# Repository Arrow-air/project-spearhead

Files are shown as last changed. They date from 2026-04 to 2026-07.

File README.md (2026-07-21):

# Project Spearhead

**An open-source fixed-wing VTOL aircraft for long-endurance missions.**

Project Spearhead is a ~25 kg MTOW hybrid quadplane developed by
[Arrow](https://arrowair.com): electric motors provide vertical takeoff
and landing, while an internal-combustion pusher engine is intended to provide
efficient long-range cruise.

Spearhead targets long-endurance work such as survey, rural surveillance, and
light cargo. Just as importantly, it is Arrow's first fixed-wing aircraft of
the current era — a deliberate learning platform for fixed-wing sizing, hybrid
propulsion, transition flight, and long-range operations on the path toward
larger aircraft.

## Status

**Phase 1 (electric flight validation) — PT1 prototype build in progress.**

The first prototype is being built in Ankara, Türkiye: laser-cut plywood ribs
and spars, carbon-fiber structure, Oratex fabric skin, 3D-printed structural
connectors, and a fully connectorized electrical harness. PT1 flies electric-only; the
internal-combustion cruise system comes in Phase 2.

The aircraft is still being validated, so requirements and component choices
are provisional unless captured in a dated document in `docs/`.

## Documentation

Start with the [project intro](docs/index.md). The `docs/` folder is the
living engineering record and is published to the Arrow docs site.

| Resource | Description |
|---|---|
| [Electrical Master Document](docs/electrical-master.md) | Full electrical architecture (SPH-E-001) |
| [PT1 Parts List](docs/pt1-parts-list.md) | Electrical procurement for the PT1 build |
| [Information Notes](docs/information-note/) | Aerodynamics and flight-dynamics design notes |
| [Reference Guides](docs/reference-guide/) | Stable technical references (e.g. ArduPilot QuadPlane) |

## Repository structure

```
project-spearhead/
├── docs/                        # Documentation (published to arrowair.com)
│   ├── information-note/        # Dated engineering information notes
│   └── reference-guide/         # Stable technical reference material
└── src/
    └── tools/                   # Engineering tools
        ├── initial_sizing/      # Aircraft sizing studies
        ├── propulsion_model/    # Propulsion modeling
        └── flight_dynamics_model/  # Flight dynamics / stability analysis
```

## Project phases

1. **Electric flight validation** — build and fly the airframe on electric
   VTOL propulsion only; validate hover, transition surfaces, and structure.
2. **Hybrid integration** — add the IC pusher engine, fuel and cooling
   systems; validate vibration handling, transition, and cruise flight.
3. **BVLOS and long-range testing** — telemetry range, lost-link behavior,
   and recovery protocols.
4. **Operational tailoring** — mission configurations (survey/cargo pods),
   operating limits, and a performance manual.

## Getting involved

- Read the [project intro](docs/index.md) and [CONTRIBUTING.md](CONTRIBUTING.md).
- Join the [Arrow Discord](https://discord.gg/arrow) — Spearhead has a weekly
  technical call and active build discussion.
- The original project proposal lives on the
  [Arrow DAO forum](https://dao.arrowair.com/t/project-spearhead-proposal-discussion/153).

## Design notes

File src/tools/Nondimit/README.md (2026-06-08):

# Nondimit v1.1 One Pager

## Purpose

Nondimit is a standalone desktop tool for turning dense aerodynamic force and moment tables into coefficient database files. It is intended for AeroDB and CFD export workflows where the source file contains dimensional forces and moments over alpha and beta, and the final file needs nondimensional body and wind-frame coefficients.

The tool can also reopen an existing Nondimit export and modify it without rerunning CFD. This can be used to move the moment reference center, change the nondimensionalization reference values, or do both in the same saved file.

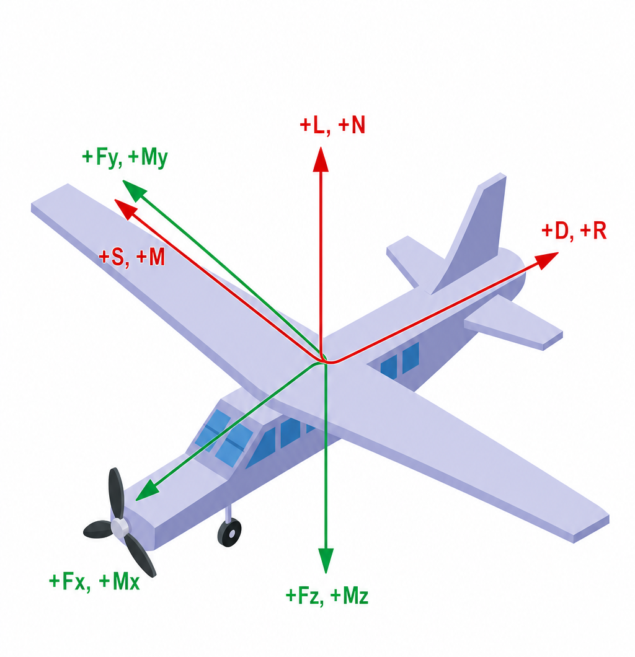
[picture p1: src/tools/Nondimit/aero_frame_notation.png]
Nondimit reference frame notation


The illustration shows the force and moment directions. The table below defines the body and wind-frame notation used by the tool.

| Frame axis | Force name | Moment name | Force coefficient | Moment coefficient | Positive direction |
| --- | --- | --- | --- | --- | --- |
| Body `+x` | `Fx` | `Mx` | `cfx` | `cmx` | Forward toward the nose. |
| Body `+y` | `Fy` | `My` | `cfy` | `cmy` | Toward the aircraft right wing. |
| Body `+z` | `Fz` | `Mz` | `cfz` | `cmz` | Down. |
| Wind `+x` | `D` | `R` | `cd` | `cr` | Aft along the drag direction, opposite the velocity direction. |
| Wind `+y` | `S` | `M` | `cs` | `cm` | Side direction. At zero beta this matches body `+y`. |
| Wind `+z` | `L` | `N` | `cl` | `cn` | Up along the lift direction. |

## Launch

The shared source, README, changelog, version file, and reference-frame image are kept in the Nondimit root folder. Platform-specific package files are separated into `windows/` and `macos/`.

On Windows, open:

```text
windows/Nondimit.exe
```

On macOS, use one of these paths:

- For a packaged app, open the provided `Nondimit.app`.
- For the source folder, run `macos/Start_Nondimit.command`.
- If macOS blocks an unsigned app, use right click, then Open.

The macOS launcher opens the packaged app if present. Otherwise it starts the shared `nondimit.py` source with Python 3.

## Main Workflows

### Convert Raw Table

Use this tab when starting from a raw dense CSV with dimensional force and moment columns.

1. Select the input CSV.
2. Choose the output path.
3. Enter reference values:
   - density `rho`
   - reference area `S`
   - velocity `V`
   - span for roll and yaw moments
   - chord for pitch moment
   - output rounding accuracy
4. Set optional force and moment corrections.
5. Enter old and new moment centers in body-axis coordinates.
6. Confirm column mapping for alpha, beta, `Fx`, `Fy`, `Fz`, and optionally `Mx`, `My`, `Mz`.
7. Set optional beta-zero cleanup and output group order.
8. Click `Convert and Save`.

If moments are mapped, the tool writes force and moment coefficients. If moment columns are not mapped, it writes force coefficients only.

### Modify Export

Use this tab when you already have a coefficient CSV from Nondimit and need to change the moment center, the nondimensionalization reference values, or the output formatting.

1. Select the existing Nondimit export.
2. The tool reads the metadata rows and fills in `rho`, `S`, `V`, span, chord, output accuracy, and current moment center.
3. Edit the reference values if the output should use a different nondimensionalization.
4. Set optional force and moment corrections.
5. Enter the new body-axis moment center if the moment reference should move. Leave it equal to the current center if only the reference values should change.
6. Confirm alpha and beta columns.
7. Set optional beta-zero cleanup and output group order.
8. Click `Modify and Save`.

The current center is read from `moment_center_body_xyz` in the input file metadata. Older exports that used `new_moment_center_body_xyz` still load correctly. New output metadata reports only the final selected moment center, not the previous center.

The reference values in this tab are intentionally editable. When **rho**, **S**, **V**, span, or chord are changed, the tool recalculates all force and moment coefficients with the edited values:

$$
q = \frac{1}{2}\rho V^2
$$

$$
\text{force denominator} = qS
$$

$$
\text{roll and yaw moment denominator} = qSb
$$

$$
\text{pitch moment denominator} = qSc
$$

Normal Nondimit exports include dimensional body force and moment columns, so the tool preserves the physical forces and moments, applies any requested moment-center shift, and then writes new coefficients from the edited reference values. If an export has been manually stripped down to coefficient-only columns, do not use this tab to change reference values, because the physical forces and moments cannot be recovered unambiguously.

## Optional Output Controls

### Force and Moment Corrections

The Corrections section can apply a multiplier and an additive delta to every force and moment component. The correction frame controls which component names are used:

| Frame | Force components | Moment components |
| --- | --- | --- |
| None | no correction | no correction |
| Body | Fx, Fy, Fz | Mx, My, Mz |
| Wind | D, S, L | R, M, N |

Each corrected component is calculated as:

$$
X_{corrected} = m_X X_{original} + \Delta X
$$

For the known missing-component drag correction, use the Wind frame and set D multiplier to 1.3. Leave S, L, R, M, and N multipliers at 1.0 and all deltas at 0.0 unless there is separate calibration evidence for those components.

When the Wind frame is selected, the tool projects the body-axis vector into the wind frame using alpha and beta, applies the selected multipliers and deltas, and reconstructs the body-axis vector before writing the final body and wind columns. This keeps Fx/Fy/Fz and D/S/L internally consistent. Moment corrections work the same way for Mx/My/Mz and R/M/N.

Force corrections are applied before moment-center shifting, so a moment-center shift uses the corrected force vector. Direct moment corrections are applied after the moment-center shift.

### Beta = 0 Cleanup

The checkboxes `Fy`, `Mx`, and `Mz` force those components to zero only on rows where beta is numerically zero. This is useful for symmetric prop-off databases where small solver noise should not create side force, roll moment, or yaw moment at zero sideslip.

The cleanup is applied before coefficients and wind-frame values are written, so body and wind outputs remain internally consistent. Selected cleanup options are stored in metadata as `zero_at_beta0`.

### Output Group Order

The ordered list controls how the generated output columns are arranged. The four groups are:

- Body Forces: `Fx`, `Fy`, `Fz`
- Body Moments: `Mx`, `My`, `Mz`
- Wind Forces: `D`, `S`, `L`
- Wind Moments: `R`, `M`, `N`

Use `Up`, `Down`, and `Reset` to reorder them. Each group keeps its coefficient columns and dimensional columns together. The selected order is stored in metadata as `output_group_order`.

## Coordinate and Coefficient Conventions

The tool uses standard aircraft body axes and aerodynamic wind-axis notation.

Body frame directions are `x` forward, `y` right, and `z` downward. Wind-frame directions are `D` aft along the drag direction, `S` sideways, and `L` upward. The moment symbols `R`, `M`, and `N` are the wind-frame roll, pitch, and yaw moments about those same wind-frame axes.

The generated body coefficient columns are:

```text
cfx, cfy, cfz
cmx, cmy, cmz
```

The generated wind coefficient columns are:

```text
cd, cs, cl
cr, cm, cn
```

The generated dimensional body and wind columns are:

```text
Fx, Fy, Fz
Mx, My, Mz
D, S, L
R, M, N
```

Nondimensionalization and dimensionalization use the reference values written in the export metadata. The dynamic pressure and denominators are:

$$
q = \frac{1}{2}\rho V^2
$$

$$
\text{force denominator} = qS
$$

$$
\text{roll and yaw moment denominator} = qSb
$$

$$
\text{pitch moment denominator} = qSc
$$

Body-axis force coefficients are:

$$
C_{F_x} = \frac{F_x}{qS}
$$

$$
C_{F_y} = \frac{F_y}{qS}
$$

$$
C_{F_z} = \frac{F_z}{qS}
$$

Wind-frame force coefficients are:

$$
C_D = \frac{D}{qS}
$$

$$
C_S = \frac{S_w}{qS}
$$

$$
C_L = \frac{L}{qS}
$$

Body-axis moment coefficients are:

$$
C_{M_x} = \frac{M_x}{qSb}
$$

$$
C_{M_y} = \frac{M_y}{qSc}
$$

$$
C_{M_z} = \frac{M_z}{qSb}
$$

Wind-frame moment coefficients are:

$$
C_R = \frac{R}{qSb}
$$

$$
C_M = \frac{M}{qSc}
$$

$$
C_N = \frac{N}{qSb}
$$

To recover dimensional values from coefficients, use the inverse form:

$$
F_x = C_{F_x}\,qS, \quad F_y = C_{F_y}\,qS, \quad F_z = C_{F_z}\,qS
$$

$$
D = C_D\,qS, \quad S_w = C_S\,qS, \quad L = C_L\,qS
$$

$$
M_x = C_{M_x}\,qSb, \quad M_y = C_{M_y}\,qSc, \quad M_z = C_{M_z}\,qSb
$$

$$
R = C_R\,qSb, \quad M = C_M\,qSc, \quad N = C_N\,qSb
$$

In the equations above, $S_w$ is the wind-frame side force. The corresponding output column is named **S**.

## Moment Center Operation

Moment shifting is done in body axes before coefficient conversion:

$$
\mathbf{M}_{new} = \mathbf{M}_{old} + \mathbf{r}_{new \rightarrow old} \times \mathbf{F}
$$

where:

$$
\mathbf{r}_{new \rightarrow old} = \mathbf{x}_{old\ center} - \mathbf{x}_{new\ center}
$$

After the body-axis moment is shifted, the tool projects both force and moment vectors into the wind frame using the row's alpha and beta.

## Output File

The saved CSV starts with a short readable metadata block, then the normal CSV header row, then table data. The metadata block is intentionally kept to only a few comment rows: reference values, final body-axis moment center, and source/options. It reports only the final moment reference center used by the exported coefficients. Selected correction frame, force multipliers, force deltas, moment multipliers, and moment deltas are stored in the options row.

Generated columns include body and wind-frame coefficients plus dimensional body and wind-frame force and moment columns. Numeric table cells are rounded to the requested output accuracy.

Recommended sanity checks after export:

- Beta-zero rows have `Fy`, `Mx`, and `Mz` equal to zero if those cleanup options were selected.
- Moment signs change as expected when moving the reference center.
- Force and moment correction metadata matches the intended frame, multipliers, and deltas.
- Metadata values match the intended `rho`, `S`, `V`, span, chord, and final moment center.

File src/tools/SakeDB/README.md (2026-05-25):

# SakeDB v1.0 Quick Start

SakeDB is a desktop workflow tool for building aerodynamic databases from high-fidelity analysis cases. It manages the sampling plan, prepares each case folder, launches a user-defined external runner, tracks progress, and exports dense force and moment tables for flight dynamics and control work.

## Purpose

Aerodynamic databases need broad coverage across angle of attack, sideslip, and later control-surface deflections. Running every possible point directly is expensive. SakeDB reduces this cost by combining anchor cases, Latin-hypercube sampling, adaptive infill, and surrogate-surface export into one traceable workflow.

## What It Does

| Function | Role |
|---|---|
| Study setup | Stores variables, bounds, outputs, budgets, anchors, symmetry settings, and runner settings in a **.sakedb** file |
| Case management | Creates one folder per analysis case and records artifacts, status, timing, and output paths |
| Sampling | Runs anchors first, then initial DOE points, then adaptive infill based on uncertainty, curvature, and spacing |
| Pause and resume | Stops or resumes studies without losing completed results |
| Discard control | Lets a bad current or completed case be excluded from surrogate fitting |
| Export | Writes raw results, symmetric results, and dense surrogate tables for downstream coefficient conversion |

## Runner Model

SakeDB is intentionally runner-neutral. A study defines an external runner, a model or mesh file, a setup script, and a launcher script. The launcher is responsible for executing the high-fidelity analysis and writing the expected output files. SakeDB then reads the requested force and moment columns and updates the study database.

The default template does not prefill a solver product or local program path. Each project supplies its own runner settings inside the study folder.

| Setting | Meaning |
|---|---|
| **sim_file** | The base model, mesh, or case file used by the external analysis. Keep it in the study folder for simple relative paths. SakeDB passes its path to the launcher as **SAKEDB_SIM_FILE** and **AERODB_SIM_FILE**. The launcher opens it directly and runs it with the setup file in the case folder |
| **setup_file** | A setup script or template copied into each case folder. SakeDB patches its **alpha** and **beta** definitions for the current sample point before the launcher runs |
| **run_script** | A launcher script copied into each case folder and executed from that folder. It should run the external analysis, write **output.out**, write **output.dat**, and optionally write **force.png** |

The setup script must expose angle definitions in this form so SakeDB can replace the contents for each case:

**double[] alpha = { 0.0 };**

**double[] beta = { 0.0 };**

The important part is the **alpha = { ... };** and **beta = { ... };** pattern. During a run, SakeDB rewrites those values with the current sample, for example **alpha = { -5.0 };** and **beta = { 10.0 };**.

For each sample, SakeDB creates a case folder such as **runs/cases/0007_infill_a-05.000_b+10.000**. That folder contains the patched setup script and copied launcher script. The launcher runs from inside this folder, using the environment variables supplied by SakeDB, and produces the case artifacts there. If a local model or mesh copy is required, the launcher should copy **SAKEDB_SIM_FILE** into the case folder before starting the analysis.

Required and expected case artifacts:

| File | Requirement |
|---|---|
| **output.out** | Text output from the external analysis. This is used for case inspection and troubleshooting |
| **output.dat** | Required force and moment table. It is also the default completion file, so the case is not accepted until it exists |
| **force.png** | Optional force-history image. If produced, it should be named exactly **force.png** so the Force Plot tab can find it |

**output.dat** must contain a **VARIABLES** header followed by numeric rows. The recommended format is:

**VARIABLES = "Beta" "Alpha" "Fx" "Fy" "Fz" "Mx" "My" "Mz"**

**10.0 -5.0 -12.3456 4.5678 -220.1234 0.1000 95.2000 -0.0300**

The force and moment columns **Fx**, **Fy**, **Fz**, **Mx**, **My**, and **Mz** are required. Column names are read from the quoted **VARIABLES** header, and numeric values may use standard decimal or scientific notation. A single final row is sufficient. If several complete rows are written, SakeDB uses the final rows according to the driver averaging setting.

## How To Use

Keep **SakeDB.exe**, **_internal**, **assets**, and **template.sakedb** together in the same folder, then launch **SakeDB.exe**. Use **New** to create a study from the bundled template or **Open** to load an existing **.sakedb** file. Put the model file, setup script, and launcher script beside the study file when you want simple relative paths.

You can also open a study directly from Windows by choosing **Open with** and selecting **SakeDB.exe** for a **.sakedb** file. Windows passes the study path to SakeDB, and SakeDB loads that study at startup. For this to work on another computer, copy the whole SakeDB folder, not only **SakeDB.exe**.

1. Define the study in **Setup**: set the study name, run folder, run budget, convergence stopping options, model file, setup script, launcher script, variables, export grid, and anchor points.
2. Save the study file, then press **Start**. SakeDB runs anchors first, then initial sampling, then adaptive infill.
3. Use **Pause**, **Resume**, and **Stop** from the sidebar to control a campaign. Use **Discard Current Case** when the active case is clearly bad.
4. Review sampled cases in **Samples**. Completed bad cases can be excluded with **Discard Selected Case**.
5. Press **Write Exports** when enough samples are available. SakeDB writes raw, symmetric, and dense surrogate outputs into the run folder.

| Area | Use |
|---|-----|
| Sidebar and status | Select study and run folders, start, pause, resume, stop runs, discard the current case, write exports, refresh the display, switch dark mode, and monitor state, sample count, budget, phase, current case, and stop reason |
| Setup tab | Edit the main study settings without touching YAML directly: budget, convergence threshold, model, setup, launcher files, variable bounds, export grid, anchor values, and extra anchor points |
| Samples tab | View the sample map, live current-case output, and the full results table. The table shows all samples while hiding long artifact paths and internal bookkeeping columns |
| Exports tab | Inspect generated dense export files and preview the dense force or moment table written for downstream flight-dynamics or coefficient-table work |
| Surrogate Surface tab | Select an output component and refresh a fitted surrogate surface to check trends, smoothness, and coverage |
| Force Plot tab | Select a completed case and inspect its per-case force plot when the runner produced one |
| Candidate Scores tab | Show the top current acquisition candidates from the fitted surrogate, including score, uncertainty, curvature, region, spacing, and distance terms |
| Study File tab | Edit or inspect the raw **.sakedb** YAML when an advanced setting is not exposed in the Setup tab |

## Why It Matters

SakeDB turns a large manual simulation campaign into a repeatable database process. The main benefit is not only fewer wasted cases, but cleaner traceability: every sampled point, discarded case, output artifact, symmetry operation, and dense export can be tied back to the study file and run folder.

## Near-Term Next Steps

- Add control-surface deflection dimensions or derivative tables.
- Keep the runner contract generic so future projects can connect different high-fidelity tools without changing the SakeDB workflow.

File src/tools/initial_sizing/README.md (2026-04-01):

# Aerodynamic Sizing Toolchain

Initial aerodynamic sizing for the Spearhead UAV. Determines wing area, tail incidence, cruise drag, and stall behavior for any airfoil combination from a 1,634-airfoil database.

## Quick Start

All inputs are in **`config.py`**. Edit the parameters, set the mode, and run:

```bash
python config.py
```

### Modes

| MODE | What it does |
|---|---|
| 1 | **Airfoil sweep** — tests all airfoil combinations from the database, ranks by composite score, outputs top 30 |
| 2 | **Specific sizing** — runs the sizing tool for the airfoils specified in the `AIRFOIL` dict, prints full results and L/D plots |

## File Structure

| File | Purpose |
|---|---|
| `config.py` | All inputs — aircraft parameters, airfoil selection, sweep filters, scoring weights. Single entry point. |
| `aircraft_sizing.py` | Core sizing solver — atmosphere, wing sizing, trim, drag, stall, alpha sweep |
| `airfoil_sweep.py` | Two-stage airfoil sweep — wing candidates then wing+tail combinations |
| `airfoil_db_re500000.csv` | Airfoil database at Re=500k (1,634 airfoils) |
| `airfoil_db_re1000000.csv` | Airfoil database at Re=1M (1,634 airfoils) |
| `oratex_compatibility.csv` | Airfoil concavity data for Oratex skin filter (generated by `download_geometries.py`) |

## config.py Structure

```
MODE        — 1 (sweep) or 2 (specific sizing)

AIRCRAFT    — shared by both modes
  Atmosphere, flight conditions, MTOW
  Fuselage geometry
  Wing geometry (AR, incidence, CG position)
  Tail configuration (1=V-tail, 2=conventional)
  Tail geometry (span, chord, dihedral, CG position)
  Vertical fin (config 2 only)
  Drag settings (misc factor, base drag recovery)
  Propeller thrust moment
  Tail incidence override

AIRFOIL     — used by MODE 2 (specific sizing)
  Airfoil input mode (1=DB lookup, 2=manual coefficients)
  Wing and tail airfoil names or manual aero coefficients
  Reynolds number

SWEEP       — used by MODE 1 (airfoil sweep)
  Oratex skin filter
  Excluded airfoils list
  Wing filters (cl_max, cd_0, thickness)
  Tail filters (camber, cd_0, thickness)
  Stage control (top wing candidates, skip tail)
  Scoring weights (area, drag, tail incidence, stall)
  Output options (top N, detail rank)
```

## Tail Configuration

### Config 1: V-tail / Inverse V-tail
- `tail_proj_span` = horizontal projected span
- `tail_dihedral` = panel dihedral angle (rad)
- Actual span = projected / cos(dihedral)
- Tail provides both pitch (V_h) and yaw (V_v) authority

### Config 2: Conventional tail
- `tail_proj_span` = full horizontal tail span
- `tail_dihedral` is ignored (set to 0 internally)
- `vert_chord` and `vert_span` define the separate vertical fin for V_v

## Key Equations

- **Wing area**: `S = W / (q_stall * CL_max_3d)`
- **3D lift slope** (Helmbold): `CL_alpha = a0 / (sqrt(1 + k^2) + k)` where `k = a0 / (pi * e * AR)`
- **3D cl_0 correction**: `cl_0_3d = cl_0 * (CL_alpha_3D / cl_alpha_2d)` — preserves zero-lift angle
- **Oswald efficiency** (Raymer): `e = 1.78 * (1 - 0.045 * AR^0.68) - 0.64`
- **Induced drag**: `CDi = CL^2 / (pi * AR * e)`
- **Fuselage drag**: Prandtl-Schlichting friction + Raymer form factor + Hoerner 3D base drag
- **Base drag recovery**: `D_base = D_base_full * (1 - recovery)`, default 34% recovery for pusher prop
- **Downwash**: `epsilon = factor * 2 * CL_wing / (pi * AR)`
- **V_h** (effective): `S_tail * cos(dihedral) * l_tail / (S_wing * c_wing)`
- **V_v**: `S_tail * sin(dihedral) * l_tail / (S_wing * b_wing)` (V-tail) or `S_vert * l_tail / (S_wing * b_wing)` (conventional)

## Sweep Scoring

Candidates are ranked by a weighted composite score (lower = better):

```
Score = w_area * norm(S_wing) + w_drag * norm(D_total) + w_itail * norm(|i_tail|) + w_stall * norm(M_stall_penalty)
```

Default weights (configurable in `config.py`):
- 40% wing area (smaller = lighter)
- 40% total drag (lower = more efficient)
- 10% tail incidence (closer to zero = less trim drag)
- 10% stall safety (nose-down moment preferred)

## Oratex Skin Filter

The Oratex filter excludes airfoils with concave lower surfaces (incompatible with heat-shrink skin). It requires:

1. Airfoil geometry files (`.dat`) in `../geometry/`
2. `oratex_compatibility.csv` — generated by running `download_geometries.py` in the parent `Sizing/` folder

If `oratex_compatibility.csv` is missing, the filter is automatically disabled with a warning. The sweep will still run but won't exclude concave airfoils.

## Dependencies

```
numpy
scipy
matplotlib
```

## CFD Validation

The sizing tool has been validated against RANS CFD and AVL vortex-lattice:
- Lift: within 5-6% of CFD across 0-13 deg AoA
- Drag: within 6% of CFD with the base drag recovery model
- Propeller interaction (actuator disk): confirms base drag recovery assumption

See `aero_validation_note.md` in the parent directory for full details.

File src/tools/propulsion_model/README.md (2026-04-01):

# Propulsion Model

Engine and propeller performance model for the Spearhead UAV. Computes power, thrust, fuel consumption, endurance, and transition (acceleration to cruise) for a 2-stroke gasoline engine with fixed-pitch propeller.

## Quick Start

```bash
python propulsion_model.py
```

Generates an 8-panel figure (`spearhead_engine_model.png`) and prints a console summary with cruise RPM, fuel flow, endurance, rate of climb, and prop comparison table.

## Configuration

All inputs are in the `DEFAULT_CONFIG` dict at the top of `propulsion_model.py`. Pass overrides to `make_plots()` or edit the dict directly.

## Outputs

### Figure (8 subplots)
| Plot | Description |
|---|---|
| Power & Torque vs RPM | Shaft power and torque curves from VE model |
| Static Thrust vs RPM | Multiple prop candidates, anchored to manufacturer data |
| Fuel Consumption vs RPM | Fuel flow from BSFC model |
| Endurance vs Tank Size | Tank sizing for target endurance at cruise |
| Force Balance vs Speed | Thrust and drag curves, net force |
| Airspeed vs Time | Transition simulation (acceleration to cruise) |
| Acceleration vs Speed | Net acceleration during transition |
| Distance vs Time | Ground distance covered during transition |

### Console Summary
- Cruise RPM (where thrust = drag)
- Fuel flow at cruise
- Excess power and max rate of climb
- Battery charging time from excess shaft power
- Prop comparison table across all candidates

## Models and Equations

### Engine Power
```
P = P_rated * (VE(RPM) / VE(RPM_rated)) * (RPM / RPM_rated)
```
- VE shape: quadratic + cubic around peak, asymmetric falloff (faster drop above peak)
- `VE = VE_peak * (1 - 0.55*(x-1)^2 - 0.07*(x-1)^3)` where `x = RPM/RPM_ve_peak`
- Anchored to manufacturer rated HP at rated RPM

### Torque
```
Q = P / omega = (P_kW * 1000) / (RPM * 2*pi/60)
```

### Static Thrust
```
T_static = T_anchor * prop_scale * (rho/rho_anchor) * (RPM/RPM_anchor)^(4/3)
```
- RPM^(4/3) exponent from combined P ~ RPM^2 (2-stroke) and momentum theory T ~ P^(2/3)
- Density ratio referenced to anchor test altitude (not sea level)
- Prop scaling: `(D/D_ref)^(4/3) * (p/p_ref)^(1/3)`

### Thrust in Flight
```
T = T_static * max(0, 1 - (J/J_zero)^2)
```
- Advance ratio: `J = V / (n * D)` where `n = RPM/60`
- Zero-thrust advance ratio: `J_zero = eta_pitch * (p/D)`
- `eta_pitch` = 1.10-1.30 for fixed-pitch props (thrust extends beyond geometric pitch speed)

### Propeller Efficiency
```
eta = eta_max * 4 * x * (1-x)   where x = J/J_zero
```
- Parabolic model peaking at J = 0.5 * J_zero with value eta_max
- eta = 0 at static (J=0) and at zero-thrust (J=J_zero)

### Fuel Consumption
```
fuel_flow [ml/hr] = P_shaft [kW] * BSFC [g/kWh] / 0.74 [kg/L gasoline]
```

### Drag
```
D = D_cruise * (V / V_cruise)^2
```
- Simple quadratic scaling from a single calibration point (from sizing tool)

### Transition Simulation
- 1D horizontal Euler integration, dt = 0.02 s
- `F_net = T(V, RPM) - D(V)`, `a = F_net / mass`, `V += a * dt`

## Assumptions

### Engine
- 2-stroke piston-port timing: VE curve is asymmetric with faster falloff above peak RPM
- Power scales linearly with VE and RPM: `P ~ VE * RPM` (constant displacement)
- BSFC is constant across the operating range (520 g/kWh default)
- No altitude derating on power — only thrust is density-corrected

### Propeller
- Fixed pitch — no variable-pitch or constant-speed governor
- Ct(J) follows a quadratic decay: `1 - (J/J_zero)^2`
- Pitch scaling `(p/p_ref)^(1/3)` is empirical, not derived from BEM theory
- Diameter scaling `(D/D_ref)^(4/3)` assumes engine absorbs prop load at same RPM
- eta_pitch > 1 accounts for real props producing thrust beyond geometric pitch speed
- Propeller efficiency model is a symmetric parabola — real props have an asymmetric eta(J) curve

### Thrust
- Static thrust anchored to a single manufacturer data point (9 kg @ 7900 RPM, 20x10 prop)
- RPM^(4/3) scaling assumes P ~ RPM^2, which is approximate for 2-strokes above torque peak
- Density correction is linear: `T ~ rho` (momentum theory gives `T ~ rho^(1/3)` at constant power, but combined engine+prop gives ~linear)
- No compressibility, no tip Mach effects

### Drag
- Quadratic V^2 scaling from a single point — does not capture the induced drag polar shape
- No density correction on drag (drag_cruise_N is assumed at mission altitude)

### Transition
- Level flight only — no ground roll friction, no climb, no wind
- Constant RPM throughout transition (no throttle modulation)
- Euler integration (first-order, dt = 0.02 s)

## Dependencies

```
numpy
matplotlib
```

## Calibration Data

| Parameter | Value | Source |
|---|---|---|
| Rated HP | 4.1 HP @ 9000 RPM | RCGF Stinger 35cc RE datasheet |
| VE peak RPM | 7500 RPM | Typical for piston-port 2-stroke |
| BSFC | 520 g/kWh | Typical for small 2-stroke (not measured) |
| Anchor thrust | 9 kg @ 7900 RPM | Manufacturer test, 20x10 prop, ~100 m altitude |
| eta_pitch | 1.20 | Typical for fixed-pitch RC props (1.10-1.30) |
| eta_prop_max | 0.70 | Typical for fixed-pitch (0.60-0.75) |
| D_cruise | 30 N @ 25 m/s | From initial sizing tool |

## Validation

### Thermal Efficiency
The model's BSFC of 520 g/kWh yields a thermal efficiency of 16.0%, calculated as:

```
eta_th = 3600 / (BSFC [g/kWh] * LHV [kJ/g])
       = 3600 / (520 * 43.4)
       = 16.0%
```

This is consistent with published data for small piston-port 2-stroke engines:

| Engine class | BSFC (g/kWh) | Thermal eff. |
|---|---|---|
| Small RC 2-stroke (piston-port) | 450 - 600 | 14 - 18% |
| Tuned 2-stroke (DI / stratified) | 320 - 450 | 18 - 26% |
| Small 4-stroke (Saito, OS) | 290 - 370 | 22 - 28% |
| Automotive gasoline | 240 - 280 | 30 - 35% |

The RCGF Stinger 35cc RE is a piston-port 2-stroke with no fuel injection or tuned exhaust, placing it squarely in the 14-18% range. No dyno data is available for this specific engine; the BSFC of 520 g/kWh is an estimate based on the engine class, not a measurement.

### Thrust Anchor
Static thrust is anchored to a single manufacturer test point (9 kg at 7900 RPM with a 20x10 prop at ~100 m altitude). The density ratio correction uses the anchor altitude as reference, so the anchor point reproduces exactly at its test conditions. Thrust at other RPMs and altitudes is extrapolated via the RPM^(4/3) scaling law.

### Cruise RPM
The cruise RPM solver finds the operating point where thrust equals drag at 25 m/s. For the 20x10 prop at 2000 m altitude, this yields ~7000 RPM. No flight test data is available for comparison.

### Limitations
- BSFC is assumed constant across all RPMs. In reality it varies by 20-30% between peak torque and maximum RPM.
- The thrust model has no compressibility or tip Mach correction — valid for tip speeds below ~200 m/s (Mach 0.6).
- The Ct(J) quadratic model is a simplification of the real thrust coefficient curve, which is typically more linear in the mid-J range.
- Propeller efficiency uses a symmetric parabolic model; real eta(J) curves are asymmetric with a sharper cutoff near J_zero.

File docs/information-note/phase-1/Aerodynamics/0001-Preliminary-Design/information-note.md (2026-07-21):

---
title: "Preliminary Exterior Design"
sidebar_label: "Information Note"
sidebar_position: 1
---

## Status

`Valid`

`Revision History: None`

`Replacement Log: None`

`Reference: None`

## Project Description

This information note documents the preliminary exterior design of Project Spearhead. The scope is the outer geometry: fuselage body, main wing, inverse V-tail, and the two longitudinal booms that carry the VTOL lift stations and support the aft tail geometry.

The design is a high-wing quadplane pusher layout. The central fuselage provides the main payload and systems volume. Two longitudinal side booms run parallel to the fuselage centerline and place the four VTOL lift disks around the wing and fuselage. The aft end of the boom system supports the inverse V-tail.

The resulting geometry will be used as a reference for structural design and aerodynamic database generation.

| Isometric view |
|----------------|
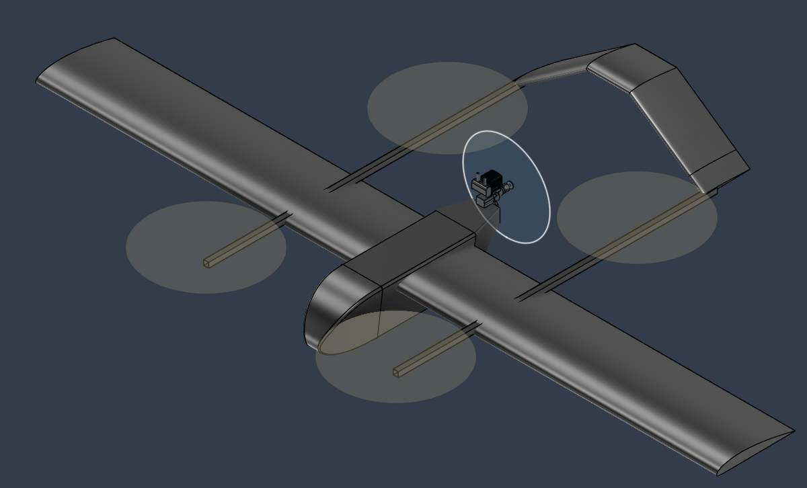
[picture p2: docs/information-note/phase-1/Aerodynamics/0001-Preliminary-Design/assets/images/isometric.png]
Isometric exterior view
|  |

## Methodology

### 1. Fuselage Sizing Method

The fuselage exterior was sized from IC engine placement first. The cylinder was intentionally left outside the fuselage to improve cooling. The engine and exposed cylinder were placed above the aft fuselage and aligned with the upper exterior flow path for cleaner airflow around the cooling region. The IC engine and related systems are covered by the aft fuselage fairing.

The aft taper is intentionally short and sharp. A longer or fuller aft body would block more of the rear pusher propeller inflow, so the body is cut back quickly behind the main volume. Curvature was not added to the aft transition for the prototype because it would make Oratex covering more difficult. This is an accepted prototype compromise and can be smoothed later if needed.

After the IC engine placement, a 12S 16000 mAh battery and a 6 L fuel tank were placed inside the fuselage. The fuel tank was centered on the CG so that the CG does not shift significantly with fuel burn during flight. This section is covered by the mid fuselage fairing.

The nose was then designed to reduce drag while considering weight. The nose houses the avionics if the CG area has no room due to the structural elements.

### 2. Wing and Tail Sizing Method

The main wing and tail geometry were sized using the aerodynamic sizing tool. The tool was used for the main wing airfoil, tail airfoil, planform parameters, incidence values, and the longitudinal spacing between the main wing and tail.

The wing and tail spacing is defined using aerodynamic-center stations relative to the CG. The selected spacing is used with the chosen airfoils and planforms to satisfy cruise trim and tail volume requirements. The tail incidence is then solved by the sizing tool for zero-elevator cruise trim.

### 3. Longitudinal Boom Layout Method

The exterior design uses two straight longitudinal booms, one on each side of the fuselage.

The lateral boom station was checked visually against the top and front views. The longitudinal positioning places the VTOL motor stations around the CG.

### 4. Tail Horizontal Wing Section

Due to the electrical elements and avionics in the tail region, the center of the tail wing is left horizontal. This section provides housing while making the access hatch easier to use.

## Results and Deliverables

### Fuselage Geometry

| Section | Length | Section size |
|---|---|---|
| Nose | About 355 mm | Expands to 240 mm by 275 mm |
| Mid body | About 540 mm | Constant 240 mm by 275 mm |
| Aft body | About 200 mm | Tapers to about 120 mm by 80 mm |
| Total | 1095 mm | 240 mm max width, 275 mm max height |

### Fuselage Sizing Inputs

| Package item | Sizing role |
|---|---|
| IC Engine | 35cc 2-Stroke IC Engine inside the fuselage |
| 12S 16000 mah battery | Primary power source inside fuselage |
| 6 L fuel tank | Cruise fuel source inside fuselage |

### Main Wing Geometry

| Parameter | Value |
|---|---|
| Airfoil | Clark Z |
| Planform | Rectangular, unswept, untapered |
| Gross span | 3.95 m |
| Effective span | 3.65 m |
| Chord | 0.457 m |
| Gross area | 1.805 m2 |
| Effective area | 1.668 m2 |
| Effective aspect ratio | 8.0 |
| Incidence | 1.0 deg |
| Maximum thickness | 54 mm |

### Tail Geometry

| Parameter | Value |
|---|---|
| Tail airfoil | NACA 0015 |
| Tail type | Inverse V-tail |
| Projected span | 1.100 m |
| Geometric span | 1.343 m |
| Chord | 0.28 m |
| Area | 0.376 m2 |
| Dihedral | 35 deg |
| Incidence | 2.0 deg |

### Main and Tail Wings Positioning

| Station | Value |
|---|---|
| Main wing AC relative to CG | 0.15 m forward |
| Tail AC relative to CG | 1.15 m aft |
| Main wing AC to tail AC distance | 1.30 m |

### Longitudinal Boom Layout

| Parameter | Value or description |
|---|---|
| Boom count | 2 |
| Orientation | Longitudinal, parallel to fuselage centerline |
| Lateral station | About 550 mm from centerline |
| Length | 2 m |
| VTOL lift stations | Four total, two per boom, 700 mm longitudinal distance from CG |

| Side view |
|-----------|
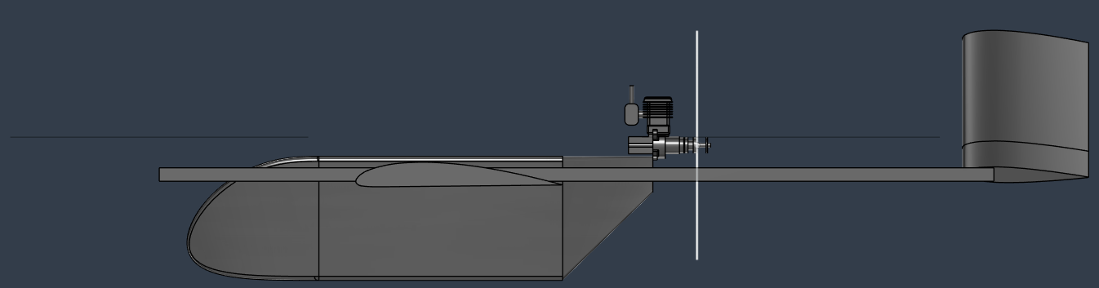
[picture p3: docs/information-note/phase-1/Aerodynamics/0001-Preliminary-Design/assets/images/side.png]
Side exterior view
|  |

| Front view |
|------------|
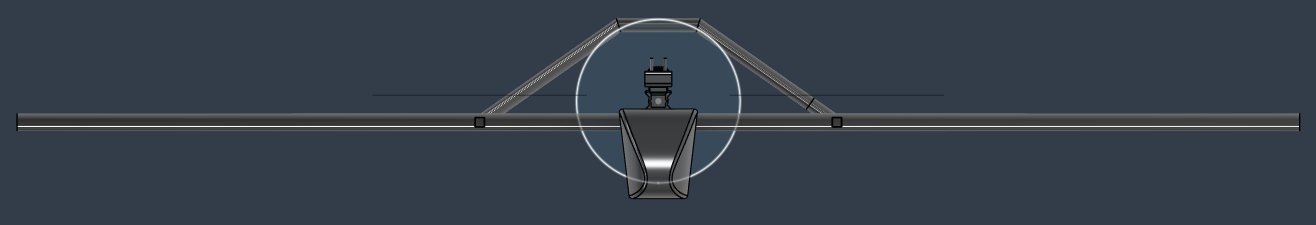
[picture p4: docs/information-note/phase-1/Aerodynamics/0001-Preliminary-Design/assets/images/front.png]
Front exterior view
|  |

| Top view |
|----------|
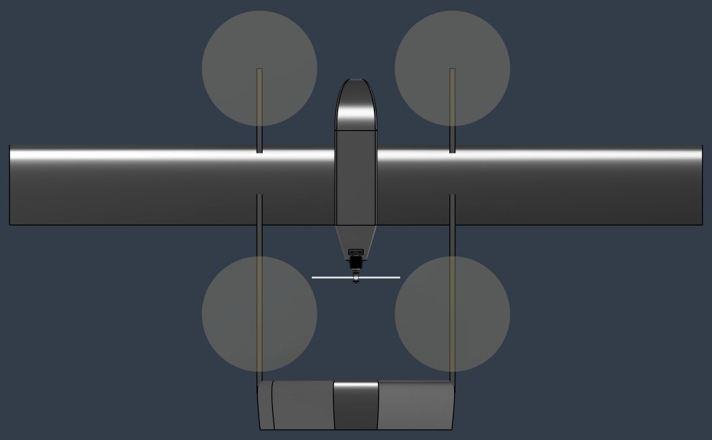
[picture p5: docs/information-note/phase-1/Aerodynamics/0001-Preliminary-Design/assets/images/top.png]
Top exterior view
|  |

### Source Files

| File |
|-----|
| [Fuselage CAD model](assets/fuselage.step) |
| [Main wing CAD model](assets/main_wing.step) |
| [Tail wing CAD model](assets/tail_wing.step) |
| [Longitudinal Booms CAD model](assets/longitudinal_booms.step) |
| [Wing/tail sizing config](assets/config.py) |
| [Wing/tail sizing results](assets/sweep_results_re500000.txt) |

## Remarks

- This note is intentionally limited to exterior geometry and the sizing drivers that define that geometry.
- The sharp aft transition and lack of curvature are known prototype compromises. They are accepted for now to protect rear pusher propeller inflow and simplify Oratex covering.

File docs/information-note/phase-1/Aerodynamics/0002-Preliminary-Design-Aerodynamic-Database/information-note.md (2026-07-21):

---
title: "Preliminary Design Aerodynamic Database"
sidebar_label: "Information Note"
sidebar_position: 1
---

# Preliminary Design Aerodynamic Database

## Status

"Valid"

"Revision History: None"

"Replacement Log: None"

"Reference: [0001-Preliminary-Design](../0001-Preliminary-Design/information-note.md)"

## Project Description

This information note documents the preliminary design aerodynamic database generation work for Project Spearhead. The purpose of the database is to provide force, moment, and coefficient data over the aircraft angle-of-attack and sideslip envelope, so that the results can be used for flight dynamics modelling, control simulation, and later flight-control table generation.

[SakeDB](https://github.com/Arrow-air/project-spearhead/blob/main/src/tools/SakeDB/README.md) was used to define and manage the CFD campaign. First, 80 CFD analyses were solved with the actuator disk model (ADM) simulating the pusher propeller. After that, 800 CFD analyses were solved without the actuator disk model. A surrogate surface was generated from the 800-case database, and the 80-case ADM database was used to apply a correction factor to the surrogate surface. Finally, the corrected dense output was processed with [Nondimit](https://github.com/Arrow-air/project-spearhead/blob/main/src/tools/Nondimit/README.md) for coefficient-table preparation, drag correction for omitted components, and sign-convention checks.

This note does not describe the internal operation of SakeDB or Nondimit. It records how the tools were used in the aerodynamic database workflow and what was delivered.

## Methodology

### 1. CFD Run Methodology

Each database point was solved as a steady incompressible CFD case. The analyses used a segregated flow solver with a K-Omega turbulence model. All Y+ wall treatment was used with five boundary-layer prism layers targeted at Y+ > 30. The computational mesh used approximately 2.7 million polyhedral cells.

Each analysis was run for 350 iterations. The accepted cases reached convergence within this iteration count based on the monitored residual and force histories.

The actuator disk campaign used a prescribed pusher actuator disk thrust of 30 N.

SakeDB was used to manage the selected alpha-beta sample points, launch the external CFD runner, and collect the completed body-axis force and moment outputs: "Fx", "Fy", "Fz", "Mx", "My", and "Mz".

| Figure | Status |
|---|---|
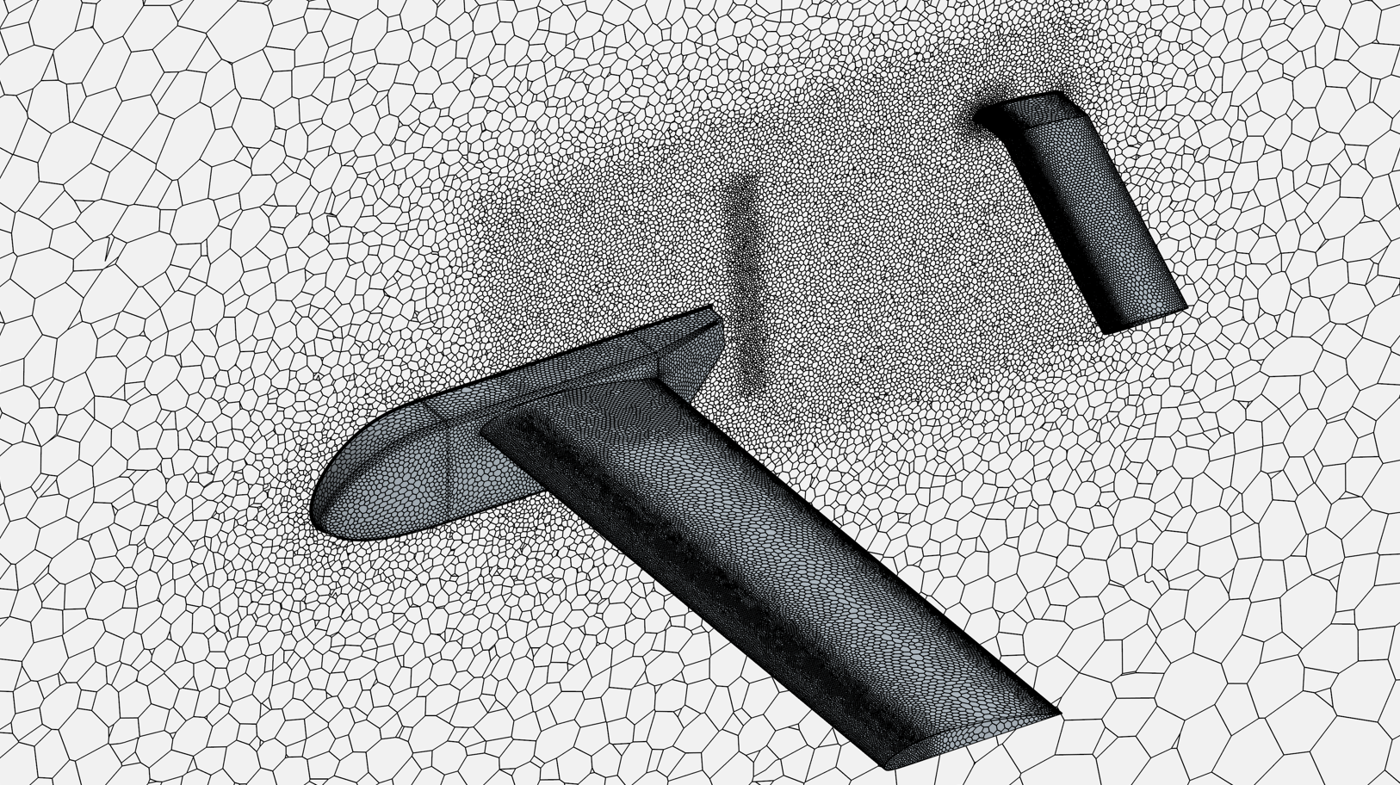
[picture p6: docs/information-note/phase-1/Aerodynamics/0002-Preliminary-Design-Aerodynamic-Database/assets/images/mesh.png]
Mesh Plot
| Mesh plot | |
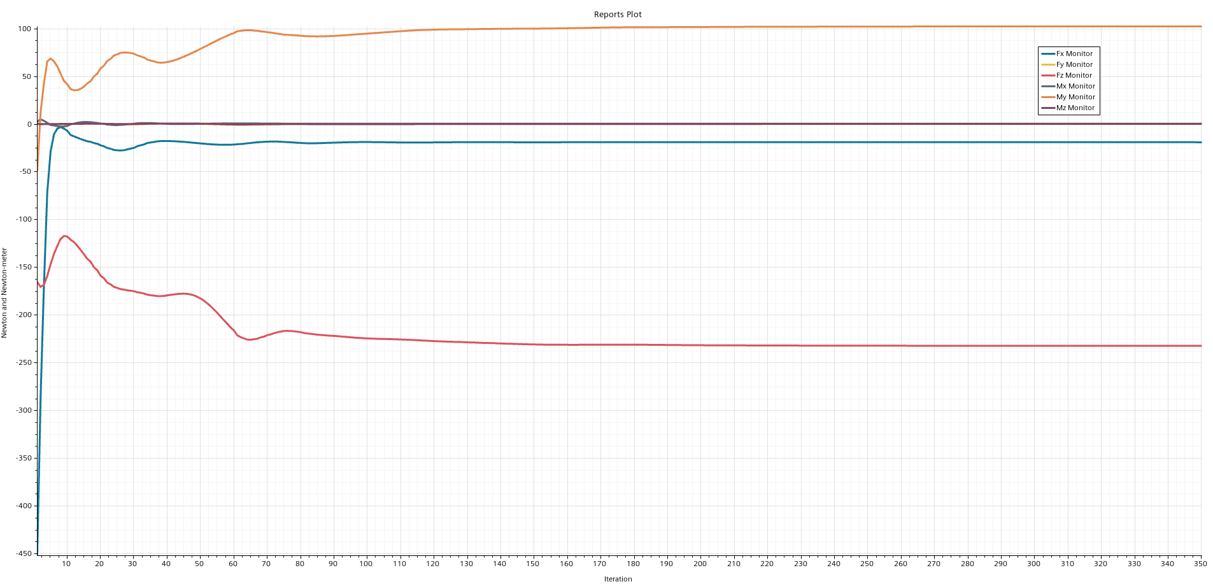
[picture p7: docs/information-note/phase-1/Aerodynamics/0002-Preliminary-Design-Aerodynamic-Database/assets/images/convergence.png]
Convergence Plot
| Convergence plot |  |
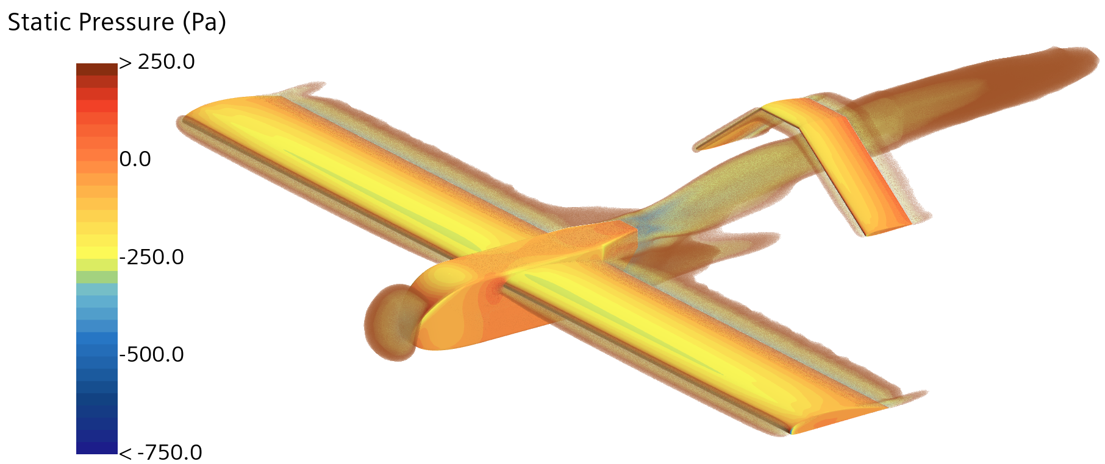
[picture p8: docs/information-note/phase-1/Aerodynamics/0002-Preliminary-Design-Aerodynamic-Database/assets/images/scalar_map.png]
Scalar Map
| Representative CFD result |  |

### 2. Actuator Disk Database

The first database was generated with the actuator disk model. This database includes 80 CFD analyses and is used to capture the aerodynamic effect of the pusher propeller model.

This database is not used as the full final surface by itself. It is used as the correction source for the larger no-actuator-disk surrogate surface.

### 3. No-Actuator-Disk Database

The second database was generated without the actuator disk model. This database includes 800 CFD analyses and covers the broader aircraft angle-of-attack and sideslip envelope.

The no-actuator-disk database is used as the main aerodynamic surface because it has much wider coverage and more sample points than the actuator disk database.

### 4. Surrogate Surface Generation

After the 800-case no-actuator-disk database was completed, a surrogate surface was generated from these results. This surface is used to create a dense aerodynamic table over the complete database range.

The database variables are alpha and beta. The delivered dense grid covers alpha from -90 deg to +90 deg and beta from -90 deg to +90 deg at 1 deg increments, for 181 x 181 points and 32,761 total rows. The exported outputs are dimensional body-axis force and moment components: "Fx", "Fy", "Fz", "Mx", "My", and "Mz".

### 5. Correction Factor Application

The actuator-disk database was then compared with the corresponding no-actuator-disk database values. From this comparison, a correction factor was applied to the surrogate surface.

This correction transfers the propeller model effect from the 80 actuator-disk analyses onto the larger 800-case surrogate surface. The corrected surface is treated as the completed aerodynamic database for this stage.

### 6. Coefficient Output Preparation

The corrected dense force and moment output was then processed with Nondimit. Nondimit was used to convert dimensional body-axis forces and moments into body and wind-frame aerodynamic coefficients, apply the selected moment reference center, and check the drag, lift, side-force, and moment sign conventions.

The coefficient workflow uses body axes with "x" forward, "y" right, and "z" down. Drag is positive aft along the wind direction, lift is positive upward, and side force is positive to the right in the wind-frame convention used by the tool.

The ADM-corrected dense dimensional table uses body-axis coordinates with its moment reference center at (-0.6 m, 0 m, 0 m). The delivered coefficient tables are recentered to the aircraft CG at (-0.15 m, 0 m, 0.15 m) in the same body-axis frame.

A wind-frame drag multiplier of 1.3 was applied during coefficient output preparation to account for known drag-producing components that were not included in the CFD geometry. This correction was applied only to the wind-frame drag component "D". The corrected drag vector was then projected back into body axes so that "Fx", "Fy", "Fz" and "D", "S", "L" remain internally consistent. No independent side-force, lift-force, or direct moment multiplier was applied for this correction.

This drag multiplier is a post-processing correction for the preliminary design aerodynamic database. It is separate from the actuator-disk correction used to transfer pusher propeller effects onto the surrogate surface. This processing step prepares the final coefficient tables for flight dynamics and control-table use.

## Results and Deliverables

### Database Package

The current database package is presented as **ADB v1.1** for the preliminary design aerodynamic database. This keeps the current release tied to the preliminary design stage while leaving room for later project phases to use higher major versions.

Instead of treating every intermediate support table as a deliverable, the database package will provide three primary tables.

| Deliverable | Description |
|---|---|
| [ADM-corrected dense table](assets/dense_table_adm_correction.csv) | No-actuator-disk dense table corrected using the 80-case ADM database |
| [Aerodynamic database](assets/adb_v1_1_no_correction.csv) | ADM-corrected dense table converted into body and wind-frame aerodynamic coefficients with the coefficient tool |
| [Drag-corrected aerodynamic database](assets/adb_v1_1_drag_correction.csv) | Aerodynamic database after the 1.3x drag multiplier for omitted drag-producing components |

The coefficient-table deliverables were generated from the ADM-corrected dense table using Nondimit. If another coefficient format, output group order, reference value set, moment reference center, or correction setup is required, users can reload the ADM-corrected dense table in Nondimit and regenerate the database export. Note that the ADM-corrected dense table moment center is (-0.6 m, 0 m, 0 m) in body-axis coordinates. The delivered coefficient tables are referenced to the aircraft CG at (-0.15 m, 0 m, 0.15 m).

| Drag | Lift |
|---|---|
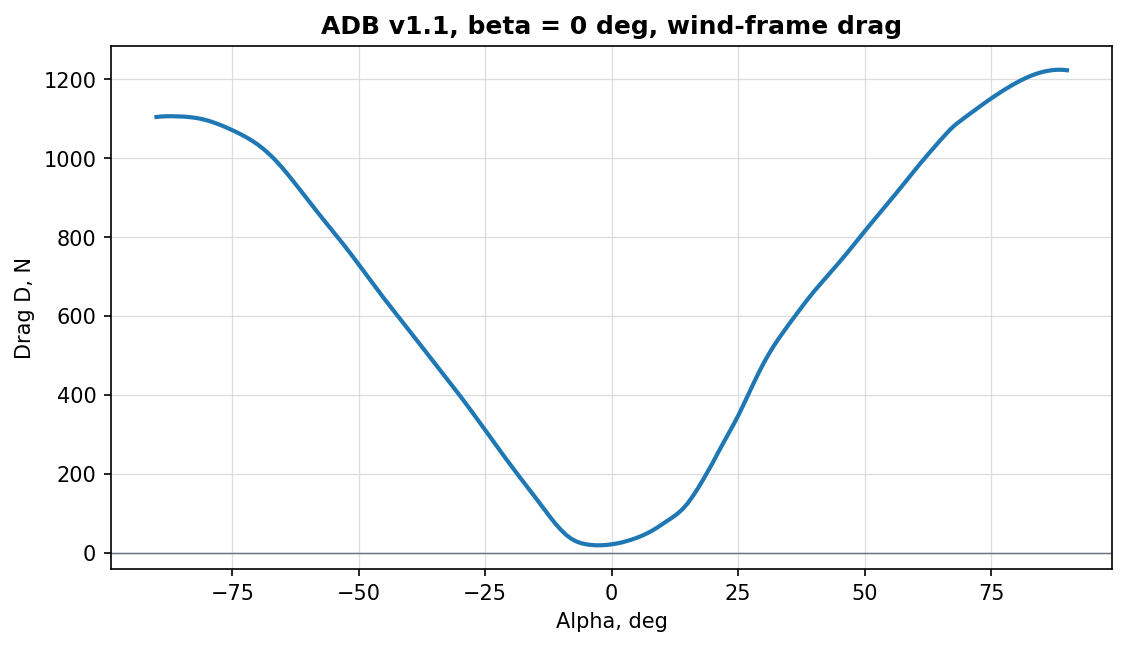
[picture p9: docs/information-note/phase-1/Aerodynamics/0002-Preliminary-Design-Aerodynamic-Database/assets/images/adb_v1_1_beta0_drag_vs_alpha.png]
Beta 0 drag versus alpha
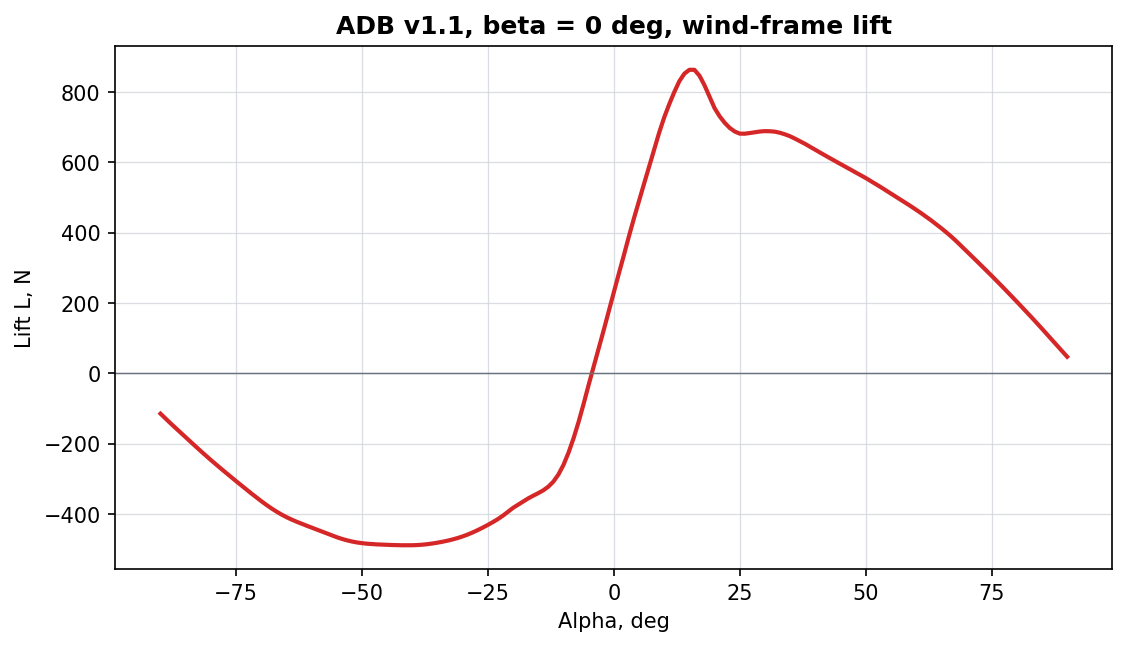
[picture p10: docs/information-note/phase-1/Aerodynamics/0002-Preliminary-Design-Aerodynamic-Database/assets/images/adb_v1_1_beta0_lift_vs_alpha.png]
Beta 0 lift versus alpha
|  |  | 
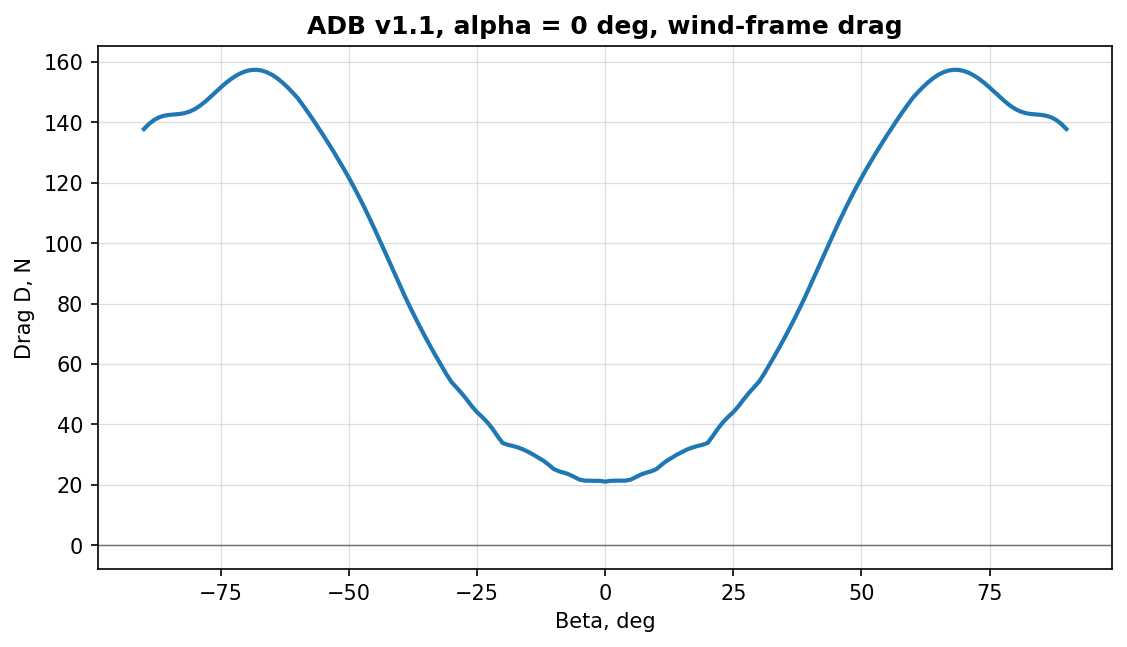
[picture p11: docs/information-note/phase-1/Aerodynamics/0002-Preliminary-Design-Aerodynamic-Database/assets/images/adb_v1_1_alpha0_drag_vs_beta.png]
Alpha 0 drag versus beta
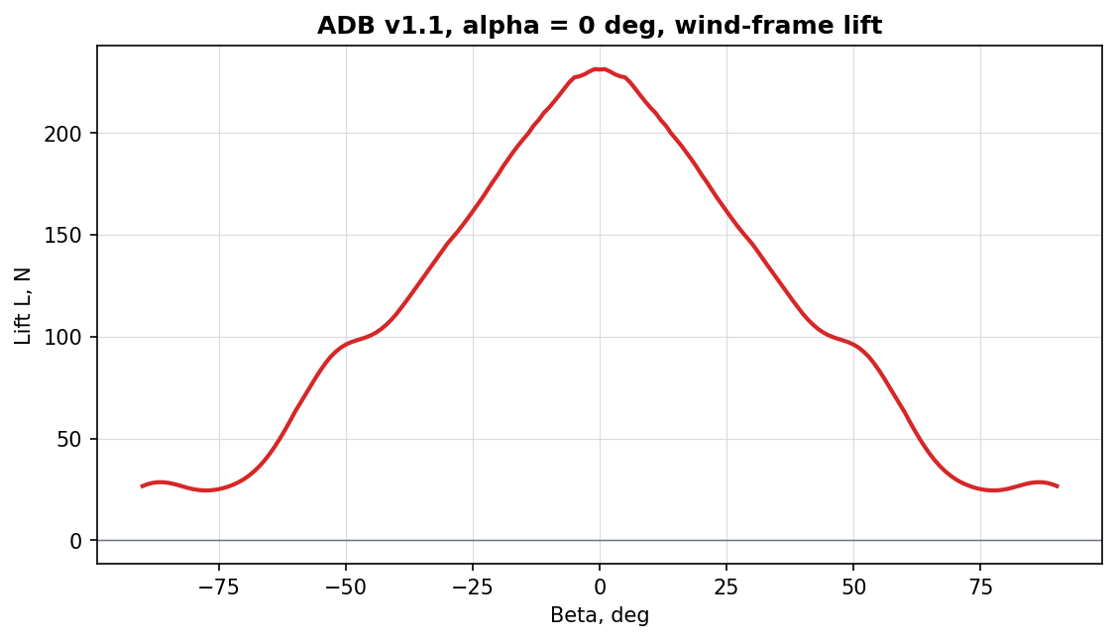
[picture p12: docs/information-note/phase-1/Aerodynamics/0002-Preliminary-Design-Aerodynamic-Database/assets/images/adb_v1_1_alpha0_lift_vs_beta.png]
Alpha 0 lift versus beta
| | |

### How to Use the Database

For preliminary design, flight-dynamics modelling, and control-table preparation, it is recommended to use **Drag-corrected aerodynamic database** as the main aerodynamic database. The 1.3x wind-frame drag multiplier was applied to cover known drag-producing equipment and installation details that were omitted from the CFD geometry. This gives a more conservative drag estimate for the current design stage and should be revisited when those components are modelled directly or when higher-fidelity validation data becomes available.

The coefficient table is organized by alpha and beta in degrees. The delivered coefficient grid covers alpha from -90 deg to +90 deg and beta from -90 deg to +90 deg at 1 deg increments, for 32,761 total rows. Users should interpolate within the provided alpha-beta grid and avoid extrapolating outside this range. The coefficient columns are dimensionless and should be dimensionalized using the reference values below.

| Reference | Symbol | Value |
|---|---|---|
| Air density | $$\rho$$ | 1.09 kg/m^3 |
| Reference velocity | $$V$$ | 25 m/s |
| Dynamic pressure | $$q = 0.5 \rho V^{2}$$ | 340.625 Pa |
| Reference area | $$S$$ | 1.805 m^2 |
| Reference span | $$b$$ | 3.95 m |
| Reference chord | $$c$$ | 0.457 m |
| Force denominator | $$qS$$ | 614.8281 N |
| Roll and yaw moment denominator | $$qSb$$ | 2428.5711 N m |
| Pitch moment denominator | $$qSc$$ | 280.9765 N m |
| Moment reference center / CG, body x y z | $$(x_m, y_m, z_m)$$ | -0.15 m, 0 m, 0.15 m |

The density value corresponds to the database run condition at 1200 m altitude.

The dynamic pressure and denominators are:

$$
q = \frac{1}{2} \rho V^{2}
$$

Wind-frame forces are dimensionalized as:

$$
D = C_D qS
$$

$$
S_w = C_S qS
$$

$$
L = C_L qS
$$

Body-axis forces are dimensionalized as:

$$
F_x = C_{F_x} qS
$$

$$
F_y = C_{F_y} qS
$$

$$
F_z = C_{F_z} qS
$$

Body-axis moments are dimensionalized as:

$$
M_x = C_{M_x} qSb
$$

$$
M_y = C_{M_y} qSc
$$

$$
M_z = C_{M_z} qSb
$$

Wind-frame moments are dimensionalized as:

$$
R = C_R qSb
$$

$$
M = C_M qSc
$$

$$
N = C_N qSb
$$

The corresponding coefficient columns in the delivered CSV are **cd**, **cs**, **cl**, **cfx**, **cfy**, **cfz**, **cmx**, **cmy**, **cmz**, **cr**, **cm**, and **cn**.

| Reference frame notation |
|--------------------------|
| Nondimit reference frame notation |

Body-axis outputs should be used when the receiving flight-dynamics model expects aircraft body axes. The body-axis convention is x forward, y right, and z down. Wind-frame outputs should be used for aerodynamic review and sign-convention checks. In the wind-frame convention used here, drag is positive aft along the wind direction, lift is positive upward, and side force is positive to the right.

If a different moment reference center, reference area, span, chord, density, or velocity is required, the table should be regenerated with Nondimit instead of manually editing the moment coefficient columns. Note that the ADM-corrected dense table moment center is (-0.6 m, 0 m, 0 m) in body-axis coordinates. The delivered coefficient tables are referenced to the aircraft CG at (-0.15 m, 0 m, 0.15 m).

## Remarks

- The actuator-disk correction and the 1.3x omitted-component drag correction are accepted for the current aerodynamic database stage.
- Preliminary pitch-moment trends indicate that the aircraft is not statically stable at the current coefficient-table CG reference by itself. This is expected to be addressed through CG placement, and the longitudinal stability analysis will define the allowable CG range and target CG location.
- This database will be updated with the control surface deflections once available.

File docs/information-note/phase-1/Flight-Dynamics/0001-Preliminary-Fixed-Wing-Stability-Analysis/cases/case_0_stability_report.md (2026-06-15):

# Case 0 Stability Report

> Preliminary FDM result: inertia, control derivatives, rate damping, and propulsion are placeholders; ADB v1.1 contains alpha-beta data only.

## Database Metadata

- File: `adb_v1_1_drag_correction_0.csv`
- Moment/reference/CG: `(-0.000, 0.000, 0.150) m`
- rho: `1.090 kg/m^3`, q_ref: `340.625 Pa`, S: `1.805 m^2`, b: `3.950 m`, c: `0.457 m`

## Trim

- success: `True`
- alpha: `2.2937 deg`
- theta: `2.2937 deg`
- elevator: `-9.7286 deg`
- throttle: `0.1719`
- residual norm: `1.415e-14`

## Static Stability Derivatives

- Cm_alpha: `-1.037054 /rad` (stable longitudinal static sign)
- Cn_beta: `+0.034377 /rad` (stable directional static sign)
- Cl_beta: `-0.013984 /rad` (stable lateral static sign)
- CL_alpha: `+5.001922 /rad`
- CY_beta: `-0.228001 /rad`

## Dynamic Modes

| Mode | Eigenvalues | wn rad/s | zeta | time constant s | Classification |
|---|---:|---:|---:|---:|---|
| phugoid | `-0.0253188+0.540732j; -0.0253188-0.540732j` | 0.5413 | 0.0468 | 39.4963 | stable |
| short_period | `-4.45612+7.50931j; -4.45612-7.50931j` | 8.7319 | 0.5103 | 0.2244 | stable |
| dutch-roll-like lateral-directional | `No clearly identifiable Dutch-roll-like lateral-directional oscillatory mode was found in this linearization.` | n/a | n/a | n/a | not identified |
| roll | `-30.2252+0j` | 30.2252 | 1.0000 | 0.0331 | stable |
| spiral | `-0.00285347+0j` | 0.0029 | 1.0000 | 350.4503 | stable |

## Summary

- Static stability: longitudinal `stable`, directional `stable`, lateral `stable`.
- Dynamic stability among identified reduced-order modes: `stable`.
- Weakly damped modes: phugoid.
- No clearly identifiable Dutch-roll-like lateral-directional oscillatory mode was found in this linearization. Because the aircraft uses an inverse V-tail/ruddervator layout and the current lateral reduced eigenspectrum is entirely real, treat this as a model limitation and classification ambiguity to investigate before flight-test use.

## Conclusion

Case 0 is the most stable sampled case by longitudinal static and dynamic metrics, but it requires the largest elevator trim deflection. It should be treated as a forward stability bound until control authority, mass properties, and the full control model are validated.

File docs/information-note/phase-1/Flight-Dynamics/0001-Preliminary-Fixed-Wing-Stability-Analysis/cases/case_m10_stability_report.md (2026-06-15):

# Case M10 Stability Report

> Preliminary FDM result: inertia, control derivatives, rate damping, and propulsion are placeholders; ADB v1.1 contains alpha-beta data only.

## Database Metadata

- File: `adb_v1_1_drag_correction_m10.csv`
- Moment/reference/CG: `(-0.100, 0.000, 0.150) m`
- rho: `1.090 kg/m^3`, q_ref: `340.625 Pa`, S: `1.805 m^2`, b: `3.950 m`, c: `0.457 m`

## Trim

- success: `True`
- alpha: `1.7432 deg`
- theta: `1.7432 deg`
- elevator: `-1.8846 deg`
- throttle: `0.1608`
- residual norm: `5.859e-14`

## Static Stability Derivatives

- Cm_alpha: `+0.446907 /rad` (unstable longitudinal static sign)
- Cn_beta: `+0.028648 /rad` (stable directional static sign)
- Cl_beta: `-0.010723 /rad` (stable lateral static sign)
- CL_alpha: `+4.858682 /rad`
- CY_beta: `-0.227790 /rad`

## Dynamic Modes

| Mode | Eigenvalues | wn rad/s | zeta | time constant s | Classification |
|---|---:|---:|---:|---:|---|
| phugoid | `-0.32842+0.893381j; -0.32842-0.893381j` | 0.9518 | 0.3450 | 3.0449 | stable |
| short_period | `-9.31431+0j; +1.1421+0j` | 1.1421 | -1.0000 | 0.8756 | unstable |
| dutch-roll-like lateral-directional | `No clearly identifiable Dutch-roll-like lateral-directional oscillatory mode was found in this linearization.` | n/a | n/a | n/a | not identified |
| roll | `-30.2281+0j` | 30.2281 | 1.0000 | 0.0331 | stable |
| spiral | `+0.000287463+0j` | 0.0003 | -1.0000 | 3478.7093 | unstable |

## Summary

- Static stability: longitudinal `unstable`, directional `stable`, lateral `stable`.
- Dynamic stability among identified reduced-order modes: `unstable`.
- Unstable modes: short_period, spiral.
- No clearly identifiable Dutch-roll-like lateral-directional oscillatory mode was found in this linearization. Because the aircraft uses an inverse V-tail/ruddervator layout and the current lateral reduced eigenspectrum is entirely real, treat this as a model limitation and classification ambiguity to investigate before flight-test use.

## Conclusion

Case M10 improves the longitudinal trend relative to nominal but remains unsuitable as a stability baseline. The pitch static derivative is still unstable, the longitudinal dynamic response is unstable, and the spiral mode is weakly unstable in this linearization.

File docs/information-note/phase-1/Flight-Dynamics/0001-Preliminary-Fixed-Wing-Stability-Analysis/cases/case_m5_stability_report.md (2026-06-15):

# Case M5 Stability Report

> Preliminary FDM result: inertia, control derivatives, rate damping, and propulsion are placeholders; ADB v1.1 contains alpha-beta data only.

## Database Metadata

- File: `adb_v1_1_drag_correction_m5.csv`
- Moment/reference/CG: `(-0.050, 0.000, 0.150) m`
- rho: `1.090 kg/m^3`, q_ref: `340.625 Pa`, S: `1.805 m^2`, b: `3.950 m`, c: `0.457 m`

## Trim

- success: `True`
- alpha: `2.0061 deg`
- theta: `2.0061 deg`
- elevator: `-5.5737 deg`
- throttle: `0.1665`
- residual norm: `4.705e-14`

## Static Stability Derivatives

- Cm_alpha: `-0.291354 /rad` (stable longitudinal static sign)
- Cn_beta: `+0.028665 /rad` (stable directional static sign)
- Cl_beta: `-0.011511 /rad` (stable lateral static sign)
- CL_alpha: `+4.932043 /rad`
- CY_beta: `-0.226353 /rad`

## Dynamic Modes

| Mode | Eigenvalues | wn rad/s | zeta | time constant s | Classification |
|---|---:|---:|---:|---:|---|
| phugoid | `-0.024601+0.474923j; -0.024601-0.474923j` | 0.4756 | 0.0517 | 40.6487 | stable |
| short_period | `-4.45504+5.15473j; -4.45504-5.15473j` | 6.8131 | 0.6539 | 0.2245 | stable |
| dutch-roll-like lateral-directional | `No clearly identifiable Dutch-roll-like lateral-directional oscillatory mode was found in this linearization.` | n/a | n/a | n/a | not identified |
| roll | `-30.2267+0j` | 30.2267 | 1.0000 | 0.0331 | stable |
| spiral | `-0.00364264+0j` | 0.0036 | 1.0000 | 274.5265 | stable |

## Summary

- Static stability: longitudinal `stable`, directional `stable`, lateral `stable`.
- Dynamic stability among identified reduced-order modes: `stable`.
- Weakly damped modes: phugoid.
- No clearly identifiable Dutch-roll-like lateral-directional oscillatory mode was found in this linearization. Because the aircraft uses an inverse V-tail/ruddervator layout and the current lateral reduced eigenspectrum is entirely real, treat this as a model limitation and classification ambiguity to investigate before flight-test use.

## Conclusion

Case M5 is the recommended near-term development baseline from this sweep. It preserves stable identified longitudinal behavior with more margin than M5p5 while staying near the transition region that should be refined in future CG studies.

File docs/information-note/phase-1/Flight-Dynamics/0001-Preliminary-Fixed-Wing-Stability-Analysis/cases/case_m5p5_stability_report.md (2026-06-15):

# Case M5p5 Stability Report

> Preliminary FDM result: inertia, control derivatives, rate damping, and propulsion are placeholders; ADB v1.1 contains alpha-beta data only.

## Database Metadata

- File: `adb_v1_1_drag_correction_m5p5.csv`
- Moment/reference/CG: `(-0.055, 0.000, 0.150) m`
- rho: `1.090 kg/m^3`, q_ref: `340.625 Pa`, S: `1.805 m^2`, b: `3.950 m`, c: `0.457 m`

## Trim

- success: `True`
- alpha: `1.9787 deg`
- theta: `1.9787 deg`
- elevator: `-5.1878 deg`
- throttle: `0.1659`
- residual norm: `2.463e-14`

## Static Stability Derivatives

- Cm_alpha: `-0.214751 /rad` (stable longitudinal static sign)
- Cn_beta: `+0.028648 /rad` (stable directional static sign)
- Cl_beta: `-0.011398 /rad` (stable lateral static sign)
- CL_alpha: `+4.924211 /rad`
- CY_beta: `-0.226440 /rad`

## Dynamic Modes

| Mode | Eigenvalues | wn rad/s | zeta | time constant s | Classification |
|---|---:|---:|---:|---:|---|
| phugoid | `-0.04536+0.166775j; -0.04536-0.166775j` | 0.1728 | 0.2624 | 22.0459 | stable |
| short_period | `-4.37067+1.2534j; -4.37067-1.2534j` | 4.5468 | 0.9613 | 0.2288 | stable |
| dutch-roll-like lateral-directional | `No clearly identifiable Dutch-roll-like lateral-directional oscillatory mode was found in this linearization.` | n/a | n/a | n/a | not identified |
| roll | `-30.2268+0j` | 30.2268 | 1.0000 | 0.0331 | stable |
| spiral | `-0.00305176+0j` | 0.0031 | 1.0000 | 327.6796 | stable |

## Summary

- Static stability: longitudinal `stable`, directional `stable`, lateral `stable`.
- Dynamic stability among identified reduced-order modes: `stable`.
- No clearly identifiable Dutch-roll-like lateral-directional oscillatory mode was found in this linearization. Because the aircraft uses an inverse V-tail/ruddervator layout and the current lateral reduced eigenspectrum is entirely real, treat this as a model limitation and classification ambiguity to investigate before flight-test use.

## Conclusion

Case M5p5 is the first sampled case with stable static pitch behavior and stable identified longitudinal modes. It should be treated as the current sampled aft boundary of the stable region rather than as a high-margin baseline.

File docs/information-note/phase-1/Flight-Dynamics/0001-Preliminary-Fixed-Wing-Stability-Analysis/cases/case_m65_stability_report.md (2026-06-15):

# Case M65 Stability Report

> Preliminary FDM result: inertia, control derivatives, rate damping, and propulsion are placeholders; ADB v1.1 contains alpha-beta data only.

## Database Metadata

- File: `adb_v1_1_drag_correction_m65.csv`
- Moment/reference/CG: `(-0.065, 0.000, 0.150) m`
- rho: `1.090 kg/m^3`, q_ref: `340.625 Pa`, S: `1.805 m^2`, b: `3.950 m`, c: `0.457 m`

## Trim

- success: `True`
- alpha: `1.9248 deg`
- theta: `1.9248 deg`
- elevator: `-4.4307 deg`
- throttle: `0.1647`
- residual norm: `2.276e-14`

## Static Stability Derivatives

- Cm_alpha: `-0.065699 /rad` (stable longitudinal static sign)
- Cn_beta: `+0.028648 /rad` (stable directional static sign)
- Cl_beta: `-0.011244 /rad` (stable lateral static sign)
- CL_alpha: `+4.908748 /rad`
- CY_beta: `-0.226749 /rad`

## Dynamic Modes

| Mode | Eigenvalues | wn rad/s | zeta | time constant s | Classification |
|---|---:|---:|---:|---:|---|
| short_period | `-6.39647+0j; -2.24543+0j; -0.442251+0j; +0.252802+0j` | 0.2528 | -1.0000 | 3.9557 | unstable |
| dutch-roll-like lateral-directional | `No clearly identifiable Dutch-roll-like lateral-directional oscillatory mode was found in this linearization.` | n/a | n/a | n/a | not identified |
| roll | `-30.2271+0j` | 30.2271 | 1.0000 | 0.0331 | stable |
| spiral | `-0.00228627+0j` | 0.0023 | 1.0000 | 437.3945 | stable |

## Summary

- Static stability: longitudinal `stable`, directional `stable`, lateral `stable`.
- Dynamic stability among identified reduced-order modes: `unstable`.
- Unstable modes: short_period.
- No clearly identifiable Dutch-roll-like lateral-directional oscillatory mode was found in this linearization. Because the aircraft uses an inverse V-tail/ruddervator layout and the current lateral reduced eigenspectrum is entirely real, treat this as a model limitation and classification ambiguity to investigate before flight-test use.

## Conclusion

Case M65 is the first sampled case with the stable sign for pitch static stability, but it is not dynamically acceptable. It helps bracket the transition region between static stability and fully stable identified longitudinal dynamics.

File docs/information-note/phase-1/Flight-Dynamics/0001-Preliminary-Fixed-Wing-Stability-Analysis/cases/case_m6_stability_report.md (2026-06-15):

# Case M6 Stability Report

> Preliminary FDM result: inertia, control derivatives, rate damping, and propulsion are placeholders; ADB v1.1 contains alpha-beta data only.

## Database Metadata

- File: `adb_v1_1_drag_correction_m6.csv`
- Moment/reference/CG: `(-0.060, 0.000, 0.150) m`
- rho: `1.090 kg/m^3`, q_ref: `340.625 Pa`, S: `1.805 m^2`, b: `3.950 m`, c: `0.457 m`

## Trim

- success: `True`
- alpha: `1.9516 deg`
- theta: `1.9516 deg`
- elevator: `-4.8077 deg`
- throttle: `0.1653`
- residual norm: `2.371e-14`

## Static Stability Derivatives

- Cm_alpha: `-0.138827 /rad` (stable longitudinal static sign)
- Cn_beta: `+0.028648 /rad` (stable directional static sign)
- Cl_beta: `-0.011321 /rad` (stable lateral static sign)
- CL_alpha: `+4.916448 /rad`
- CY_beta: `-0.226595 /rad`

## Dynamic Modes

| Mode | Eigenvalues | wn rad/s | zeta | time constant s | Classification |
|---|---:|---:|---:|---:|---|
| short_period | `-5.50085+0j; -3.20677+0j; -0.240531+0j; +0.116444+0j` | 0.1164 | -1.0000 | 8.5878 | unstable |
| dutch-roll-like lateral-directional | `No clearly identifiable Dutch-roll-like lateral-directional oscillatory mode was found in this linearization.` | n/a | n/a | n/a | not identified |
| roll | `-30.227+0j` | 30.2270 | 1.0000 | 0.0331 | stable |
| spiral | `-0.00266744+0j` | 0.0027 | 1.0000 | 374.8912 | stable |

## Summary

- Static stability: longitudinal `stable`, directional `stable`, lateral `stable`.
- Dynamic stability among identified reduced-order modes: `unstable`.
- Unstable modes: short_period.
- No clearly identifiable Dutch-roll-like lateral-directional oscillatory mode was found in this linearization. Because the aircraft uses an inverse V-tail/ruddervator layout and the current lateral reduced eigenspectrum is entirely real, treat this as a model limitation and classification ambiguity to investigate before flight-test use.

## Conclusion

Case M6 is statically stable in pitch but still dynamically unstable. It sits close to the dynamic stability transition and is useful for bounding the aft side of the stable region.

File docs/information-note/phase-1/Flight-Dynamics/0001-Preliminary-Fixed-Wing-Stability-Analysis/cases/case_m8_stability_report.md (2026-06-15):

# Case M8 Stability Report

> Preliminary FDM result: inertia, control derivatives, rate damping, and propulsion are placeholders; ADB v1.1 contains alpha-beta data only.

## Database Metadata

- File: `adb_v1_1_drag_correction_m8.csv`
- Moment/reference/CG: `(-0.080, 0.000, 0.150) m`
- rho: `1.090 kg/m^3`, q_ref: `340.625 Pa`, S: `1.805 m^2`, b: `3.950 m`, c: `0.457 m`

## Trim

- success: `True`
- alpha: `1.8458 deg`
- theta: `1.8458 deg`
- elevator: `-3.3242 deg`
- throttle: `0.1630`
- residual norm: `3.985e-14`

## Static Stability Derivatives

- Cm_alpha: `+0.155594 /rad` (unstable longitudinal static sign)
- Cn_beta: `+0.028648 /rad` (stable directional static sign)
- Cl_beta: `-0.011018 /rad` (stable lateral static sign)
- CL_alpha: `+4.886141 /rad`
- CY_beta: `-0.227202 /rad`

## Dynamic Modes

| Mode | Eigenvalues | wn rad/s | zeta | time constant s | Classification |
|---|---:|---:|---:|---:|---|
| phugoid | `-0.745163+0.728641j; -0.745163-0.728641j` | 1.0422 | 0.7150 | 1.3420 | stable |
| short_period | `-7.91482+0j; +0.574806+0j` | 0.5748 | -1.0000 | 1.7397 | unstable |
| dutch-roll-like lateral-directional | `No clearly identifiable Dutch-roll-like lateral-directional oscillatory mode was found in this linearization.` | n/a | n/a | n/a | not identified |
| roll | `-30.2275+0j` | 30.2275 | 1.0000 | 0.0331 | stable |
| spiral | `-0.00116757+0j` | 0.0012 | 1.0000 | 856.4773 | stable |

## Summary

- Static stability: longitudinal `unstable`, directional `stable`, lateral `stable`.
- Dynamic stability among identified reduced-order modes: `unstable`.
- Unstable modes: short_period.
- No clearly identifiable Dutch-roll-like lateral-directional oscillatory mode was found in this linearization. Because the aircraft uses an inverse V-tail/ruddervator layout and the current lateral reduced eigenspectrum is entirely real, treat this as a model limitation and classification ambiguity to investigate before flight-test use.

## Conclusion

Case M8 is close to the static pitch-stability transition but has not crossed into acceptable behavior. It remains statically unstable in pitch and dynamically unstable in the identified longitudinal response.

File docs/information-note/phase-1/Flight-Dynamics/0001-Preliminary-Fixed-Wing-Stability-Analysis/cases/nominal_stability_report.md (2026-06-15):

# Nominal Stability Report

> Preliminary FDM result: inertia, control derivatives, rate damping, and propulsion are placeholders; ADB v1.1 contains alpha-beta data only.

## Database Metadata

- File: `adb_v1_1_drag_correction.csv`
- Moment/reference/CG: `(-0.150, 0.000, 0.150) m`
- rho: `1.090 kg/m^3`, q_ref: `340.625 Pa`, S: `1.805 m^2`, b: `3.950 m`, c: `0.457 m`

## Trim

- success: `True`
- alpha: `1.5005 deg`
- theta: `1.5005 deg`
- elevator: `1.5157 deg`
- throttle: `0.1563`
- residual norm: `1.279e-13`

## Static Stability Derivatives

- Cm_alpha: `+0.985487 /rad` (unstable longitudinal static sign)
- Cn_beta: `+0.024349 /rad` (stable directional static sign)
- Cl_beta: `-0.010028 /rad` (stable lateral static sign)
- CL_alpha: `+4.858682 /rad`
- CY_beta: `-0.229180 /rad`

## Dynamic Modes

| Mode | Eigenvalues | wn rad/s | zeta | time constant s | Classification |
|---|---:|---:|---:|---:|---|
| phugoid | `-0.091489+0.764909j; -0.091489-0.764909j` | 0.7704 | 0.1188 | 10.9303 | stable |
| short_period | `-11.7041+0j; +3.06093+0j` | 3.0609 | -1.0000 | 0.3267 | unstable |
| dutch-roll-like lateral-directional | `No clearly identifiable Dutch-roll-like lateral-directional oscillatory mode was found in this linearization.` | n/a | n/a | n/a | not identified |
| roll | `-30.229+0j` | 30.2290 | 1.0000 | 0.0331 | stable |
| spiral | `-0.00898588+0j` | 0.0090 | 1.0000 | 111.2858 | stable |

## Summary

- Static stability: longitudinal `unstable`, directional `stable`, lateral `stable`.
- Dynamic stability among identified reduced-order modes: `unstable`.
- Weakly damped modes: phugoid.
- Unstable modes: short_period.
- No clearly identifiable Dutch-roll-like lateral-directional oscillatory mode was found in this linearization. Because the aircraft uses an inverse V-tail/ruddervator layout and the current lateral reduced eigenspectrum is entirely real, treat this as a model limitation and classification ambiguity to investigate before flight-test use.

## Conclusion

The nominal database is not an acceptable fixed-wing stability baseline in the current FDM workflow. It is statically unstable in pitch and has an unstable longitudinal dynamic mode, although it remains useful as the aft/reference starting point for the CG sensitivity sweep.

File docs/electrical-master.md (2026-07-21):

---
title: "Spearhead Electrical Master Document"
sidebar_label: "Electrical Master"
sidebar_position: 2
---

# Spearhead Electrical Master Document

**Doc ID:** SPH-E-001
**Revision:** 0.19
**Author:** errrks
**Date:** June 2026
**Status:** Phase 1 specified. Phases 2–4 are architecture stubs pending detailed design.

---

## Table of Contents

1. [Purpose and Scope](#1-purpose-and-scope)
2. [System Architecture](#2-system-architecture)
3. [Requirements Traceability](#3-requirements-traceability)
4. [Phase 1: Electric VTOL (Detailed)](#4-phase-1-electric-vtol-detailed)
   - 4.1 Battery System
   - 4.2 Power Distribution
   - 4.3 Kill Switches
   - 4.4 Voltage Regulation
   - 4.5 VTOL Motors and ESCs
   - 4.6 Wiring Harness and Connection Plan
   - 4.7 Flight Controller
   - 4.8 GPS and Navigation Sensors
   - 4.9 CAN Bus Architecture
   - 4.10 Tail Electronics
   - 4.11 Servo System
   - 4.12 Telemetry and Communications
   - 4.13 Health Monitoring
   - 4.14 Heading LEDs
   - 4.15 Component Locations
   - 4.16 Phase 1 BOM and Cost Estimate
5. [Phase 2: Hybrid Integration](#5-phase-2-hybrid-integration)
6. [Phase 3: BVLOS (Stubs)](#6-phase-3-bvlos-stubs)
7. [Phase 4: Payload Bay (Stubs)](#7-phase-4-payload-bay-stubs)
8. [Work Packages](#8-work-packages)
9. [Open Questions](#9-open-questions)
10. [Revision History](#10-revision-history)

---

## 1. Purpose and Scope

This document defines the electrical architecture for Project Spearhead across all four development phases. Phase 1 (electric VTOL validation) is specified to component level. Phases 2–4 contain architecture stubs and open questions to be resolved as the project progresses.

Scope: power system, propulsion electronics, avionics, sensor integration, communications, harness design, component layout, and per-phase work packages.

Out of scope: structural design, ArduPilot parameter tuning (see `docs/reference-guide/ardupilot-quadplane.md`), flight mechanics.

---

## 2. System Architecture

### 2.1 Power Topology

```
                     ┌──────────────────┐
                     │  12S LiPo Pack   │
                     └────────┬─────────┘
                              │  QS8-S (pack socket, anti-spark, ground safing disconnect)
                  [No hardware HV kill, PT1: software E-stop + QS8-S unplug, OQ-05 closed]
                              │  8 AWG
                        ┌─────┴──────┐
                        │ FCHUB-12S  │  44.4V nominal
                        │    PDB     │  battery pads = FC power tap point
                        └┬───┬───┬──┬┘
                        ESC1 ESC2 ESC3 ESC4  (all DroneCAN)
                          │   │   │   │
                          M1  M2  M3  M4   (FR / RL / FL / RR)

   FCHUB battery pads ─ 16 AWG XT60 pigtail ─ [PM02 V3]
                                                5.2V/3A analog → 6-pin → Pixhawk 6C POWER1
   FCHUB 440A sensor + VBat divider ─ analog ─→ Pixhawk 6C POWER2 (vehicle V/I, sense only)

                  FCHUB-12S PDB rails
                        │
          ┌─────────────┼──────────────────┐
          │             │                  │
   [5V/5A BEC]  [HV spur → Tail PM12S-3]  [12V/4A BEC]
  peripheral 5V   (Vx → ruddervators,     payload (Ph 4)
  (CAN/RC/telem)   5V → adapter+Here4)    + contactor coil
                                           if D2 picks one)

  Flaperon servo power: forward robocombo DC-DC buck @ 8.4V (HV input
  at the FCHUB pads), not shown above. See §4.4.
  Tail PM12S-3 HV input: 18 AWG branch off the ESC-lead extension
  joint at the boom root (not a FCHUB rail), behind the HV kill. See §4.10.
          │
    [LV Kill Switch]
   (FC + periph 5V)
          │
     ┌────┴──┬────────┐
  Pixhawk   GPS   Sensors/RC/
    6C    (shelf) Telemetry
 (POWER1 = PM02 V3 supply, POWER2 = FCHUB analog V/I sense)
```

### 2.2 Communications Topology

```
Pixhawk 6C
│
├── CAN1 ─── [120Ω] ── CAN splitter/hub
│        ├── ESC1..ESC4 (nodes 1–4, short boom stubs)
│        └── Here4 (tail, node 11) ── CAN-PWM adapter (node 12) ── [120Ω]
│
├── CAN2 ─── [reserved / Phase 3 expansion]
│
├── GPS1   ─── u-blox F9P primary GPS (serial, SERIALx_PROTOCOL = 5)
├── TELEM1 ─── Holybro SiK V3 telemetry radio (MAVLink 2.0; STORK-borrowed first-flight unit, long-term TBD)
├── RC IN  ─── Radiolink R9DS receiver (SBUS), paired with the AT9S Pro transmitter (D3 RC side closed June 18)
├── TELEM3 ─── [reserved / Phase 3 long-range link]
├── GPS2   ─── Ainstein US-D1 altimeter (UART; CAN alternate frees this port)
│
├── I2C   ─── [backup airspeed transducer if I2C DLVR]
├── ADC   ─── Pitot transducer (analog); POWER1/POWER2 carry battery V/I
│
├── PWM OUT (IO MAIN 8 ch + FMU AUX 8 ch):
│     Output 1: Aileron, right flaperon (physical PWM from the 6C IO)
│     Output 2: Aileron, left flaperon  (physical PWM from the 6C IO)
│     Output 3: RuddervatorLeft  (SERVO_FUNCTION 79, via DroneCAN to tail adapter, node 12)
│     Output 4: RuddervatorRight (SERVO_FUNCTION 80, via DroneCAN to tail adapter, node 12)
│     Outputs 5–8: VTOL motor commands via DroneCAN ESC nodes 1–4 (no physical PWM)
│
└── USB-C ─── Ground configuration / parameter upload
```

VTOL motor commands go over DroneCAN via ESC_BM bitmask. Physical PWM outputs 5–8 are unused in Phase 1 unless DroneCAN falls back to PWM.

CAN bus length nose to tail: approximately 2.5 m. No signal integrity issue at 1 Mbps for this length.

### 2.3 Physical Location Overview

| Zone | Contents |
|---|---|
| Nose (slimmed, v5) | No avionics requirement. Pitot mast and external antenna placement only if needed |
| Forward battery bay | motorobit 12S 22Ah 15C solid-state pack (3,709g, 190×78×126mm), QS8-S socket (anti-spark, ground safing disconnect), HV kill (implementation TBD, OQ-05). Moved forward for CG per the v5 layout |
| Avionics shelf (above battery, top access) | Pixhawk 6C, PM02 V3 analog power module (FC POWER1 supply; POWER2 = FCHUB analog V/I sense), primary GPS (F9P, serial) on the shelf cover (sky view), RC receiver, telemetry radio, LV kill switch. Compartment ~180×250mm footprint × ~90mm tall between the longerons (June 12 estimate, pending CAD) |
| CG bay / boom roots | Matek FCHUB-12S PDB (HV distribution + 5V/12V BECs, battery pads carry the FC power tap), CAN splitter/hub, forward robocombo buck (flaperon 8.4V rail) |
| Boom roots / tips (×4) | ESC externally mounted on boom near motor (within 150mm of motor centerline) |
| Motors (×4) | MAD V8013 PRO IPE 150KV, 3–5° forward tilt relative to aircraft body (motors vertical relative to gravity when aircraft is in cruise attitude) |
| Tail group (boom-mounted) | Here4 (secondary GPS), Matek CAN-L4-PWM CAN-to-PWM adapter, PM12S-3 (Vx servo rail + fixed 5V for adapter and Here4), ruddervator servo connectors |
| Wing panels (×2) | Flaperon servos (Kingmax CLS3015S, 8.4V), wing panel connector (signal + 8.4V + GND, 8.4V from the forward robocombo buck) |
| Airframe exterior | WS2812 heading LED strips (wing tips, nose, tail) |

Zones follow Alperen's fuselage conceptual v5 (June 11): longer thinner nose, forward battery for CG, avionics shelf above the battery with top access, pusher between the fuselage and the boom-carried tail. The tail harness (CAN trunk + HV spur) therefore routes along a tail boom, not through a fuselage run. Shelf and bay dimensions are open, see the open-question list in `docs/pt1-electrical-information-note.md` (SPH-E-002).

---

## 3. Requirements Traceability

Derived from the Project Spearhead DAO proposal (AIP-006, March 2026) and meeting decisions through May 2026. The formal project charter referenced in proposal §5 has not yet been published to the repo. Until then, the AIP-006 proposal text is the authoritative requirements source.

| ID | Requirement | Phase | Source |
|---|---|---|---|
| E-REQ-01 | VTOL thrust-to-weight ≥ 1.5:1 at MTOW 25 kg | 1 | AIP-006 §9.2 |
| E-REQ-02 | Independent hardware kill switches for HV and LV. **PT1 deviation (June 17):** LV hardware kill only; HV path uses software E-stop + QS8-S unplug, no hardware HV kill (recorded §9.3 deviation, see §4.3). Full HV kill returns for the final product | 1 | AIP-006 §9.3 |
| E-REQ-03 | Real-time telemetry: battery SoC, generator output (Phase 2+), fuel level (Phase 2+) | 1/2 | AIP-006 §9.3, §9.5 |
| E-REQ-04 | Redundant GPS | 1 | AIP-006 §9.4 |
| E-REQ-05 | Radar or laser altimeter | 1 | AIP-006 §9.4 |
| E-REQ-06 | Front-facing obstacle avoidance sensor | 3 | AIP-006 §9.4 |
| E-REQ-07 | Long-range telemetry > 200 km | 3 | AIP-006 §9.5, §9.6 |
| E-REQ-08 | Secondary short-range RF link for local ops | 1 | AIP-006 §9.5 |
| E-REQ-09 | Payload bay: 12V power, CAN or Ethernet, quick-release | 4 | AIP-006 §9.7 |
| E-REQ-10 | Pre-flight diagnostics: battery, GPS, altimeter, sensor health | 1 | AIP-006 §9.8 |
| E-REQ-11 | Heading indicator LEDs | 1 | AIP-006 §9.8 |
| E-REQ-12 | Link-loss and engine-out autonomous recovery | 1/2 | AIP-006 §9.8, §2.5 |
| E-REQ-13 | Pixhawk-standard FC with quadplane transition logic | 1 | AIP-006 §9.4 |
| E-REQ-14 | IC engine ignition and optional starter | 2 | AIP-006 §9.2 |
| E-REQ-15 | Generator: avionics power and battery recharge during cruise | 2 | AIP-006 §9.3 |

---

## 4. Phase 1: Electric VTOL (Detailed)

Phase 1 scope: all systems needed for VTOL hover, control surface authority, structural validation, and detachable wing testing. No IC engine. No generator.

---

### 4.1 Battery System

#### Sizing

Based on the MAD V8013 PRO 150KV datasheet (measured at 48V, 25°C, sea level with FLUXER PRO 26×7.8 MATT prop):

**Datasheet voltage vs. 12S operating voltage:**

A 12S LiPo charges to 50.4V (4.2V/cell) and the datasheet was measured at 48V — placing the test conditions squarely within the normal mid-flight range of a 12S pack. The datasheet numbers are therefore directly representative rather than requiring large corrections. As the battery discharges, bus voltage drops and the motor must spin faster (more throttle) to maintain the same thrust, increasing current draw. The motor's operating zone shifts progressively across a flight.

Required thrust per motor: 25,000 g / 4 = **6,250 gf**

**Hover operating point across battery discharge (sea level):**

| Battery state | Bus voltage | Throttle (approx.) | Current/motor | Total draw | Motor zone |
|---|---|---|---|---|---|
| Full charge | 50.4V | ~57% | ~17A | ~68A | Continuous |
| ~75% SoC (matches datasheet) | 48V | ~60% | ~19.8A | ~79A | Continuous |
| ~50% SoC | 45V | ~63% | ~22A | ~88A | Continuous |
| Nominal | 44.4V | ~65% | ~24.4A | ~98A | Continuous / edge |
| Low battery warning | 42V | ~68% | ~28A | ~112A | Short-term zone |

Motor operating zones from datasheet footnote (motor thermal limits, not ESC limits — see §4.13):
- **Below 24A/motor:** Sustainable continuous
- **24–78A/motor:** Short-term only, ~10–30s
- **Above 78A/motor:** Non-working

The motor operates in the continuous zone for most of the usable flight window. It only enters the short-term zone near the low-battery warning threshold (42V / 3.5V/cell) — which is also the point at which landing should already be initiated. At altitude (1,200m, ~12% lower air density), add approximately 2–3% throttle to each row above, nudging the nominal and low-battery points further into short-term territory.

**Battery capacity sizing:** the QuadPlane hovers only during VTOL takeoff, landing, and transition and flies wing-borne the rest of the mission, so sustained hover is not the energy driver. At ~85A average hover draw a 22 Ah pack gives roughly 15 minutes of hover before reserve, well beyond the per-flight hover budget for Phase 1 testing and transitions. The pack selected June 17, 2026 is the **22,000 mAh** (12S) motorobit solid-state LiPo (3,709g, 190×78×126mm, QS8-S), superseding the 16 Ah ProFuse picked June 11. This returns capacity to the earlier 22 Ah figure with no weight penalty: at 3,709g it is ~113g lighter than the 3,822g 16 Ah ProFuse, so the solid-state cell density offsets the extra capacity and the May mission-energy weight trade (which had dropped to 16 Ah to save ~1.7 kg) no longer applies.

**Peak current** (safety-margin thrust at 75% throttle, 36.6A/motor × 4):
- 4 × 36.6A = **146A** (short-term zone, < 30s)
- At 22,000 mAh: 146 / 22 = **6.6C**. The 320A ESC-capped absolute peak is 14.5C, still inside the pack's 15C / 330A continuous rating

**Thrust-to-weight at max thrust** (100% throttle, 15,032 gf/motor × 4 = 60,128 gf = 61.3 kg):
- T/W = 61.3 / 25 = **2.45:1** (E-REQ-01 of 1.5:1 exceeded)

#### Specification

| Parameter | Target |
|---|---|
| Chemistry | LiPo, high-discharge |
| Cell count | 12S |
| Nominal voltage | 44.4V |
| Full charge | 50.4V |
| Low-battery cutoff | 3.5V/cell → 42V pack (ArduPilot warning), 3.3V/cell → 39.6V (critical) |
| Capacity | **22,000 mAh** (12S, motorobit solid-state pack, selected June 17, 2026) |
| C-rating | 15C (330A continuous). Meets the ≥15C floor exactly. 330A continuous covers even the 320A ESC-capped absolute peak, but expect more voltage sag under the peak than the 60C ProFuse showed — verify on the first high-throttle hover |
| Connector | **QS8-S socket on the pack** (Amass QS8, anti-spark, ~120A continuous class). Harness side: QS8-S plug, 8 AWG to the FCHUB battery pads. Anti-spark, so there is no mating spark at 12S (see the §4.3 connector note). No Y-splitter: the FC power module taps the FCHUB pads |
| Form factor | **Selected June 17: 12S 22,000 mAh 15C semi-solid LiPo** (~290–300 Wh/kg; vendor lists it as "solid-state"; sourced from motorobit, TR), single pack, **190×78×126mm**, QS8-S socket. Length 190mm drives the forward bay (34mm shorter than the ProFuse's 160mm height). Lock position with Alperen before the fuselage is built |
| Weight | **3,709g**, largest single CG impact item. ~113g lighter than the 16Ah ProFuse despite +6Ah, so the May weight trade is moot |

**Dumb LiPo pack (no BMS or CAN).** A standard high-discharge 12S LiPo is used, not a smart battery. Alperen found the smart-battery option added roughly 1 kg, not worth it for the end product. Implications:
- No CAN battery telemetry and no per-cell data. Vehicle current comes from the FCHUB-12S 440A sensor and pack voltage from the power module or a FC voltage sense (see §4.2 and §4.13)
- Balance leads are used for charging only, not wired into the aircraft. In flight the pack connects to the HV path by main leads only
- Set conservative pack-level low-voltage thresholds (no per-cell cutoff). Carry a plug-in cell checker for ground checks
- Pack selected June 17 (WP-E01 reopened and reclosed): motorobit 12S 22Ah 15C solid-state LiPo, 3,709g, 190×78×126mm, QS8-S socket (supersedes the ProFuse 16Ah 60C selected June 11)

---

### 4.2 Power Distribution

| Parameter | Value |
|---|---|
| Board | Matek FCHUB-12S **V2**, off-the-shelf PDB (no custom board for V1) |
| Architecture | Star: battery to the FCHUB-12S, individual leads to each ESC. The battery input pads also carry the FC power module tap (16 AWG XT60 pigtail), replacing the earlier battery Y-splitter |
| Input | 8–60V (3–12S), battery main leads only (no balance harness) |
| Per-channel rating | 70A continuous, 110A burst per ESC pad. Hover is ~24–31A per motor, peak ~80A per motor (capped by the 80A ESC), so the margin is ample |
| ESC connection | 4× ESC power pads. Only the power pads are used. The signal and telemetry pads stay unused because the ESCs run DroneCAN (see §4.9) |
| On-board BECs | 5V/5A (max 6A), 12V/4A (max 5A), 3.3V/0.5A. Rail assignment in §4.4 |
| Current sensor | On-board 440A analog sensor for vehicle current (0–3.3V over 440A; ArduPilot `BATT_AMP_PERVLT 133.3`), wired to the 6C POWER2 analog CURRENT pin. Pack voltage from the V2 built-in 1K:20K divider (V pad set to VBat, `BATT_VOLT_MULT 21.0`) to the POWER2 VOLTAGE pin. FCHUB is the primary battery monitor (BATT1), PM02 V3 on POWER1 is BATT2. See §4.13 |
| V2 breakout | JST-SH 8-pin: V (selectable 12V or VBat via the 1K:20K divider), G, Curr, TLM (BLHeli32, unused), S1–S4 (ESC signal, unused with DroneCAN). Ships with the SH1.0 8-pin cable |
| Switchable 12V | 12VSW pad, on/off via FC PINIO (GPIO level), 2A constant. Candidate supply for the EV200 contactor coil (§4.3) or a switched LED feed |
| Per-branch fusing | 100A fast-blow per ESC branch, optional for Prototype 1 (assess in WP-E02) |
| Physical | 55 × 50 × 6 mm, 30.5 × 30.5 mm Φ3 mounting, 21g. Ships with a low-ESR bulk capacitor for ESC switching transients |

The FCHUB-12S replaces the earlier custom PCB and bus bar option, in line with the V1 goal of minimizing custom boards. Holybro PM07 is not needed since the FCHUB current sensor handles vehicle-current monitoring. The 70A per-channel continuous rating comfortably exceeds the AMPX 80A ESC ceiling, and the 4×110A burst rating covers the 320A peak.

---

### 4.3 Kill Switches

| Switch | Covers | Does NOT cover | Placement | Current rating |
|---|---|---|---|---|
| HV safing (no hardware kill, PT1) | Software E-stop (ArduPilot motor emergency stop on an RC switch) cuts CAN motor commands; QS8-S anti-spark unplug for ground safing | Does not physically interrupt the armed HV bus | RC switch + accessible QS8-S | software + connector |
| LV Kill | FC power (PM02 V3 5.2V to POWER1), peripheral 5V rail (GPS, RC, telemetry) | Both servo rails: forward robocombo (flaperons) + tail PM12S-3 (ruddervators + adapter + Here4), all HV-derived | Exterior, separate | ≥ 10A |

The tail HV→5V BEC powers the ruddervator servos, the CAN-PWM adapter, and the Here4, all from the HV bus spur. The whole tail control path therefore has no separate LV kill and de-energizes only when the pack is disconnected at the QS8-S (there is no hardware HV kill for PT1, see below), preserving ruddervator authority whenever the aircraft is armed. This is intentional, and it resolves the earlier concern about the adapter losing power on an LV kill, since it no longer draws from the CAN 5V rail.

**PT1 implementation (resolved June 17: no hardware HV kill).** AIP-006 §9.3 SHALL requires independent HV and LV kill switches. For PT1 the team accepts a **recorded §9.3 deviation: no hardware HV kill.** HV-path safing is the ArduPilot software E-stop (motor emergency stop on an RC switch, with the AMPX 2 s CAN watchdog as a backstop) plus unplugging the QS8-S anti-spark connector for ground safing. The LV kill is retained. Rationale (June 12): no clean contactor placement for PT1 without extra components and mass, and the QS8-S anti-spark already manages connection inrush. The full independent HV kill returns for the final product. The June 11 RC-switchable criterion and the candidates below are kept as record (superseded for PT1):

| Candidate | How it switches | Mass | Notes |
|---|---|---|---|
| TE Kilovac EV200AAANA contactor | 12V economizer coil (1.7W hold ≈ 0.14A) from the FCHUB V2 12VSW pad, switched directly by FC PINIO. No driver hardware. RC kill via RC_OPTION relay mapping, GCS kill via MAVLink relay | ~450g | ~€149. Proven interrupt rating (2000A at 320VDC). Closing onto the discharged ESC input caps at 50V is within rating, no precharge stage needed |
| MOSFET anti-spark switch (e-skate class, 200A cont / 400A peak, up to 20S) | Enable line interfaced to an RC switch or FC GPIO | ~100–150g | ~$80. Fails short (a failed kill no longer kills), no flight heritage, enable interface is an adaptation. Bench evaluation required before trusting it in the HV path |
| Software E-stop + ground safing only | ArduPilot motor emergency stop on an RC switch cuts CAN motor commands. AMPX throttle-loss protection backstops at 2 s. Pack connector unplug for ground safing | 0g | Not a hardware kill. A recorded §9.3 deviation for PT1 only, full hardware kills return for the final product |

The software E-stop layer costs nothing and gets configured regardless of which hardware path wins. The earlier WP-E02 options table (contactor + key switch, Anderson PP75 pull disconnect, E-stop pushbutton) is superseded: none of those are RC switchable, and the PP75 was undersized anyway at 75A-class continuous against a 98–124A hover draw.

**Connector interaction (updated June 17):** the selected motorobit pack carries a **QS8-S socket, which is anti-spark**. The connector itself limits the ESC cap inrush on mating, so there is no mating spark at 12S regardless of the kill choice. This removes the earlier "plain connector" argument for an inline hardware kill. With PT1 going software-only (no hardware HV kill, decided June 17), the QS8-S anti-spark is what manages mating inrush, and no AS150U adapter is needed.

LV kill switch: illuminated rocker or key switch, 10A @ 12V. Interrupts the FC power (PM02 V3 output) and the peripheral 5V rail (GPS, RC, telemetry). It does not cut either servo rail: the forward robocombo (flaperons) and the tail PM12S-3 (ruddervators + adapter + Here4) are both HV-derived and stay powered until the pack is unplugged at the QS8-S (no hardware HV kill for PT1).

---

### 4.4 Voltage Regulation

| Rail | Voltage | Continuous Current | Loads | BEC type |
|---|---|---|---|---|
| FC power (POWER1) | 5.2V | 3A max | Pixhawk 6C (single supply on POWER1) | PM02 V3 (analog, bundled with the 6C), fed from a 16 AWG XT60 pigtail at the FCHUB battery pads. POWER2 carries the FCHUB analog V/I sense, not a power feed |
| Peripheral 5V | 5.0–5.2V | 4–6A | Shelf F9P GPS (serial), RC receiver, telemetry radio, sensors | FCHUB 5V, separate from the FC inputs. Tail devices (adapter, Here4) run on the tail PM12S-3 instead |
| LED 5V | 5V | up to ~3A | WS2812B strips (wing tips, nose, tail) | Separate feed, high transient draw, kept off the FC rail |
| Flaperon servo | 8.4V | ~2–3A/servo, 15A available | 2× Kingmax CLS3015S on wing panels | Forward robocombo DC-DC buck @ 8.4V (HV input at the FCHUB pads, 15A) via the wing connectors. See §4.11 |
| Ruddervator servo | 8V | ~2–3A/servo, 15A available | 2× Kingmax CLS3015S in tail bay | Tail PM12S-3 Vx rail (8V), fed from the HV bus spur. ~33 kg·cm at 8V vs 35 kg·cm at 8.4V, still ample. Its fixed 5V powers the adapter and Here4. No long LV run through the fuselage |
| Payload | 12V | TBD | Phase 4 only — not needed for Phase 1 | — |

FC power: the Pixhawk runs from a single source, the PM02 V3 on POWER1. POWER2 is not a backup brick — it carries the FCHUB analog V/I sense (§4.13), so for V1 we trade FC power redundancy for vehicle-current sensing. This is a single point of failure on FC power, accepted to keep V1 simple. If FC power redundancy is wanted before extended flights, move the FCHUB sense to a spare ADC and free POWER2 for a backup BEC.

**FC supply (Pixhawk 6C + PM02 V3, selected June 17):** the FC runs from the analog PM02 V3 (2–12S, bundled with the 6C at rx-dynamic) on POWER1, fed by a 16 AWG XT60 pigtail soldered at the FCHUB-12S battery input pads. The pads are the same electrical node a battery Y-splitter would create, with one fewer connector pair in the 320A path, so the earlier AS150U/XT150 Y-splitter is dropped (it remains the fallback if the pad tap proves mechanically awkward). The module carries only the FC draw. The 6C's analog POWER ports are what enable the FCHUB vehicle V/I to feed POWER2 directly (§4.13); the digital PM02D used by the earlier 6X plan could not have done this, since its V/I ride I2C.

**FCHUB-12S on-board BECs:** the FCHUB provides 5V/5A (max 6A), 12V/4A, and 3.3V/0.5A (verified against the Matek page, June 2026). With the FC on its own power module, use the FCHUB 5V for the peripheral 5V rail (F9P GPS, RC, telemetry), and the FCHUB 12V for the Phase 4 payload and the HV kill contactor coil if an EV200 or GX11 is chosen. Keep the WS2812 LED strips on a separate 5V feed so their transients stay off the peripheral rail.

BEC / servo-rail selection (updated June 17): **1× Matek PM12S-3 (tail) + 1× robocombo DC-DC buck (wing)**.
- **Tail — Matek PM12S-3** (Aykut Havacılık TR, 6,900 TL, specs verified June 2026): 9–55V input with TVS protection, Vx selectable 5.25 / 6 / 8V at 15A continuous (25A peak), fixed 5.2V/4A, fixed 12V/4A, built-in 1K:20K divider, 53g. Vx set to **8V** feeds the ruddervator servo rail (Kingmax CLS3015S), and its fixed 5V feeds the adapter logic and the Here4. Kept because it provides both the 8V servo rail and the 5V logic rail in one TVS-protected module.
- **Wing — robocombo DC-DC buck** (8–60V in, 15A adjustable): HV input at the FCHUB pads, output set to **8.4V** for the flaperon servos. Adjustability to 8.4V (which the PM12S-3 Vx cannot reach, capping at 8V) gets full Kingmax torque. Replaces the forward PM12S-3, which is dropped. Caveats: lock the output pot (threadlock), confirm it is a synchronous buck genuinely rated at 15A with heatsinking, and scope for output overshoot before a servo is connected.

This supersedes the late-June-11 "2× PM12S-3" plan and the earlier BEC12S-PRO / MBEC6S / Castle BEC Pro / PM07 candidates. PT1 runs the final 8.x V HV servos directly (no 5V test-servo stage, see §4.11).

---

### 4.5 VTOL Motors and ESCs

**Status: ordered** (6 of each, MAD Motor Poland, expected delivery 2–4 weeks from May 1, 2026; ATR certificate requested for Turkish customs — zero import tax if provided).

#### Motors

| Parameter | Value |
|---|---|
| Model | MAD V8013 PRO IPE 150KV |
| KV | 150 |
| Weight | **591 g** |
| Battery | 12S (44.4V nominal; datasheet tested at 48V) |
| Max temperature | 87°C |
| Recommended hover thrust | 4.5–6.5 kgf (Spearhead at 6.25 kgf/motor — top of range) |
| Maximum thrust | **15 kgf** (with FLUXER PRO 26×7.8 MATT at 48V) |
| Electrical efficiency | > 80% (peak ~82% at 65–75% throttle) |
| Max propeller | 26" (boom spacing constraint) |
| Auto-center feature | Magnetic/mechanical indexing: props stop parallel to boom when power removed |
| Mount pattern | 40mm bolt circle, M4×4 |
| Bearings | Dual 6901 deep-groove |
| Quantity ordered | 6 (4 installed, 2 spares) |
| Motor tilt | 3–5° forward relative to aircraft body axis. The aircraft's natural cruise attitude (nose slightly elevated from wing incidence) places the motor thrust axes approximately vertical relative to gravity during hover — the structural tilt and aircraft attitude cancel. ArduPilot level calibration must be performed with the aircraft in cruise attitude (not flat on the ground) per `docs/reference-guide/ardupilot-quadplane.md §12`. |

**Performance table** (MAD datasheet, 48V, 25°C, sea level, FLUXER PRO 26×7.8 MATT):

| Throttle | Current (A) | Input Power (W) | Thrust (gf) | Efficiency (gf/W) | Elec. eff. (%) | Zone |
|---|---|---|---|---|---|---|
| 30% | 3.5 | 169 | 1,694 | 10.0 | 68.6 | Continuous |
| 40% | 6.8 | 326 | 2,894 | 8.9 | 75.1 | Continuous |
| 50% | 11.9 | 571 | 4,355 | 7.6 | 79.5 | Continuous |
| 55% | 15.6 | 745 | 5,313 | 7.1 | 81.0 | Continuous |
| 60% | **19.8** | **945** | **6,440** | **6.8** | 82.0 | **Continuous limit ≈ here** |
| 65% | 24.4 | 1,163 | 7,318 | 6.3 | 82.2 | Short-term (10–30s) |
| 70% | 30.0 | 1,420 | 8,476 | 6.0 | 82.3 | Short-term |
| 75% | 36.6 | 1,726 | 9,759 | 5.7 | 82.1 | Short-term |
| 80% | 41.7 | 1,961 | 10,389 | 5.3 | 82.0 | Short-term |
| 90% | 58.5 | 2,718 | 12,985 | 4.8 | 80.4 | Short-term |
| 100% | 77.8 | 3,569 | 15,032 | 4.2 | 78.0 | Short-term / non-working |

**Datasheet operating zones:**
- **Below 24A (< ~62% throttle at 48V):** Sustainable continuous
- **24–78A (~62–99% throttle):** Short-term only, ~10–30 s
- **Above 78A:** Non-working zone

At Spearhead's MTOW and nominal battery voltage (44.4V), hover falls near 65% throttle at sea level and ~69% at 1,200m altitude — placing each motor at or just above the continuous zone boundary. Monitor ESC temperatures during all hover tests. Set `Q_M_THST_HOVER` accurately to minimize steady-state throttle.

**Motor wire enamel risk:** If motor phase leads are shortened, inspect strand insulation for enamel or clear varnish coating. Remove at the termination point before soldering. A coated termination creates a high-resistance joint that will overheat under load. (Ref: Feather PC3 incident — see Erick's failure notes.)

#### ESCs

| Parameter | Value |
|---|---|
| Model | MAD AMPX 80A V2 (5–14S) DroneCAN |
| Protocol | DroneCAN V2.0 (also supports CyphalCAN; also accepts PWM 1050–1940µs) |
| Continuous current | 80A (requires good heat dissipation) |
| Current limit (burst) | 84A |
| Input voltage | 5–14S, 16–64V |
| BEC output | **5V / 200mA** — insufficient for avionics; use only as CAN signal reference or auxiliary. Dedicated BECs required for avionics and servo rails. |
| CAN telemetry fields | Voltage, current, temperature, operation status (broadcast in real time over DroneCAN) |
| PWM input voltage | 3.3V or 5V compatible |
| Protection level | IP67 (fully sealed, waterproof) |
| Operating temperature | -20°C to +65°C ambient |
| Thermal protection | >125°C: output reduces to 50% max. >140°C: full shutdown; will not restore until throttle zeroed AND ESC cools to <80°C |
| Short circuit protection | Shuts down output permanently — **requires power cycle to recover**. One motor loss per flight is unrecoverable in flight. |
| Throttle loss protection | Cuts power if CAN command absent for **>2 seconds**. ArduPilot CAN bus must maintain continuous ESC commands or motors cut. |
| Startup protection | Motor must start within 10s of throttle advance or ESC shuts down |
| Voltage protection | Below 16V or above 64V: alarm and no start (disabled during flight). 12S operational range 36–50.4V is within safe limits. |
| Sync freewheeling | Supported — active energy recovery on throttle reduction. Test interaction with IPE auto-center feature. |
| Weight | ~90g (excluding wires) |
| Dimensions | 79.6 × 36.0 × 23.5mm |
| Mounting | M2×4 screw holes (4 points) |
| Power wire | 12AWG / 800mm |
| Phase wire | 14AWG / 150mm |
| Signal wire | 1000mm (bare leads: Black=GND, White=PWM, Red=CANH, Green=CANL + 5V BEC wire) |
| Quantity ordered | 6 (4 installed, 2 spares) |
| Unit price | $60 (DroneCAN V2) + $30 shipping |

DroneCAN node ID assignment:

| Node ID | Motor position | Rotation | ArduPilot servo output |
|---|---|---|---|
| 1 | Front right (M1) | CCW | Servo 5 |
| 2 | Rear left (M2) | CCW | Servo 6 |
| 3 | Front left (M3) | CW | Servo 7 |
| 4 | Rear right (M4) | CW | Servo 8 |

Key ArduPilot parameters:
```
CAN_P1_DRIVER = 1
CAN_D1_PROTOCOL = 1
CAN_D1_UC_ESC_BM = 0x000F   ; bits 0–3 enable ESC nodes 1–4
CAN_D1_UC_SRV_BM = 0x000C   ; servo outputs 3–4 (ruddervators) to the tail adapter, node 12
Q_FRAME_CLASS = 1             ; Quad
Q_FRAME_TYPE = 1              ; X
```

Full parameter list in `docs/reference-guide/ardupilot-quadplane.md`.

#### Propellers

| Parameter | Value |
|---|---|
| Model | MAD FLUXER PRO 26×7.8 MATT — 2Pcs (SKU: 0103LX0013) |
| Diameter × pitch | 660.4 × 198.1 mm (26 in × 7.8 in) |
| Material | Carbon fiber + resin |
| Finish | Matte (non-reflective) |
| Weight | **69g per blade** — 4 installed props = **276g total** |
| Type | Fixed (not folding) |
| Hub bore | Ø10mm center shaft hole |
| Hub bolt pattern | Ø20mm bolt circle, 4× M3 screws |
| Accessories included | 8× M3×14mm mounting screws, 2× cover plates per pair |
| Optimum RPM | **1,900–4,000 RPM** |
| Single thrust limit | **18 kgf** — not the binding constraint (motor limits at 15 kgf) |
| Working temperature | -40°C to +65°C |
| Quantity ordered | 6 pairs (12 blades: 6 CW + 6 CCW); 4 installed, spares absorb early breakage |
| Unit price | $193.90/pair + $59.70 shipping |
| Reasoning (fixed not folding) | Folding props risk uncontrolled rotation in forward-flight airflow and uncertain locking behavior at speed |

**Hover operating point cross-check (prop test data vs motor datasheet):**

From the standalone prop test table:

| RPM | Thrust (gf) | Output Power (W) | Prop efficiency (gf/W) |
|---|---|---|---|
| 3,226 | 4,110 | 444 | 9.3 |
| 3,619 | 5,120 | 625 | 8.2 |
| 3,971 | 6,160 | 834 | 7.4 |
| 4,232 | 6,940 | 1,008 | 6.9 |

At hover (~3,780 RPM, 44.4V nominal): interpolated ~5,700 gf, prop efficiency ~7.8 gf/W. Motor datasheet showed 6,440 gf at 3,811 RPM at 48V — consistent after accounting for voltage difference. Numbers agree across both datasheets.

Hover operating point (~3,780 RPM) falls within the 1,900–4,000 RPM optimum range.

**Hub compatibility:** The prop hub requires a 10mm shaft bore. Confirm V8013 PRO output shaft diameter is 10mm before installation. Torque plate bolt pattern (Ø20mm, M3×4) must match the motor's prop adapter plate — verify with Alperen's motor mount design.

**Weight upgrade path:** Ultra-light carbon variants (~20g savings per prop) deferred to ~August 2026 after initial testing (80g total saving across 4 props).

---

### 4.6 Wiring Harness and Connection Plan
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

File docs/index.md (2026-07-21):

---
title: Intro
sidebar_label: Intro
sidebar_position: 1
description: Introduction to Project Spearhead
---

# Project Spearhead

Project Spearhead is Arrow's ~25 kg MTOW hybrid fixed-wing VTOL aircraft
project. It is a quadplane-style platform: electric motors provide vertical
takeoff and landing, while an internal-combustion pusher engine is intended to
provide efficient cruise flight.

Spearhead is aimed at long-endurance missions such as survey, rural
surveillance, and light cargo. Just as importantly, it is a hardware learning
platform for Arrow: the project builds real experience with fixed-wing
aircraft sizing, hybrid propulsion, transition flight, long-range telemetry,
and larger aircraft systems — a deliberate step on Arrow's path toward bigger
aircraft.

These docs are a living engineering record. Spearhead is in active prototype
development, so details will change as the team builds, tests, and learns.
Treat the [DAO proposal](https://dao.arrowair.com/t/project-spearhead-proposal-discussion/153)
as the project charter and these docs as the current state of execution.

## Project goals

Spearhead is intended to develop and validate:

- Aircraft sizing and structural integrity for a 25 kg class fixed-wing VTOL
  aircraft.
- Hybrid propulsion using electric VTOL motors plus an internal-combustion
  pusher engine for cruise.
- Generator integration, cruise battery-charging strategy, and energy
  management.
- Hover-to-cruise and cruise-to-landing transition control.
- Internal-combustion engine vibration mitigation and avionics protection.
- Long-range telemetry, including RF and possible satellite-based links.
- Modular payload support for surveillance and limited cargo use cases.
- Safety and failure handling for lost-link, engine-out, and long-range
  operations.

The goal is not a polished commercial aircraft in the first pass. The goal is
a capable prototype platform and the internal know-how needed for future
larger systems.
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

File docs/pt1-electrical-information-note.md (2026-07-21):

---
title: "Spearhead PT1 Electrical Architecture and Decisions"
sidebar_label: "PT1 Architecture & Decisions"
sidebar_position: 3
---

# Spearhead PT1 Electrical Architecture and Decisions Information Note

Internal doc ID: SPH-E-002. Companion to SPH-E-001 (Spearhead Electrical Master) and SPH-E-004 (PT1 Electrical Planning and Design Foundation).

## Status

`Valid`
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

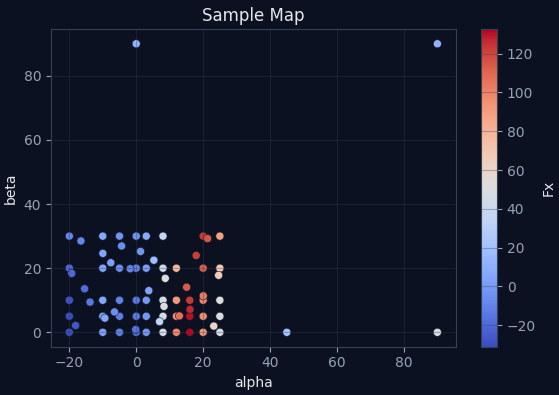
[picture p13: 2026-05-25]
docs/information-note/phase-1/Aerodynamics/0002-Preliminary-Design-Aerodynamic-Database/assets/images/sample_map_adm.png

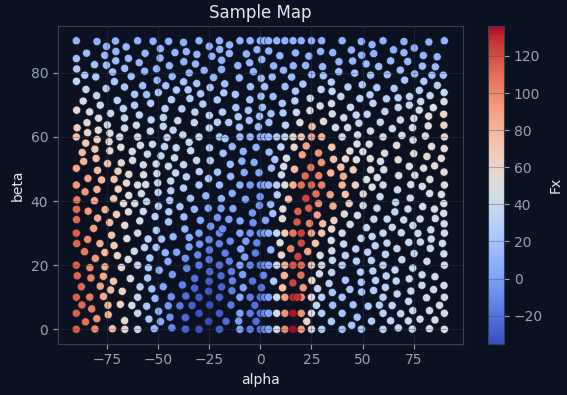
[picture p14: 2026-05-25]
docs/information-note/phase-1/Aerodynamics/0002-Preliminary-Design-Aerodynamic-Database/assets/images/sample_map.png

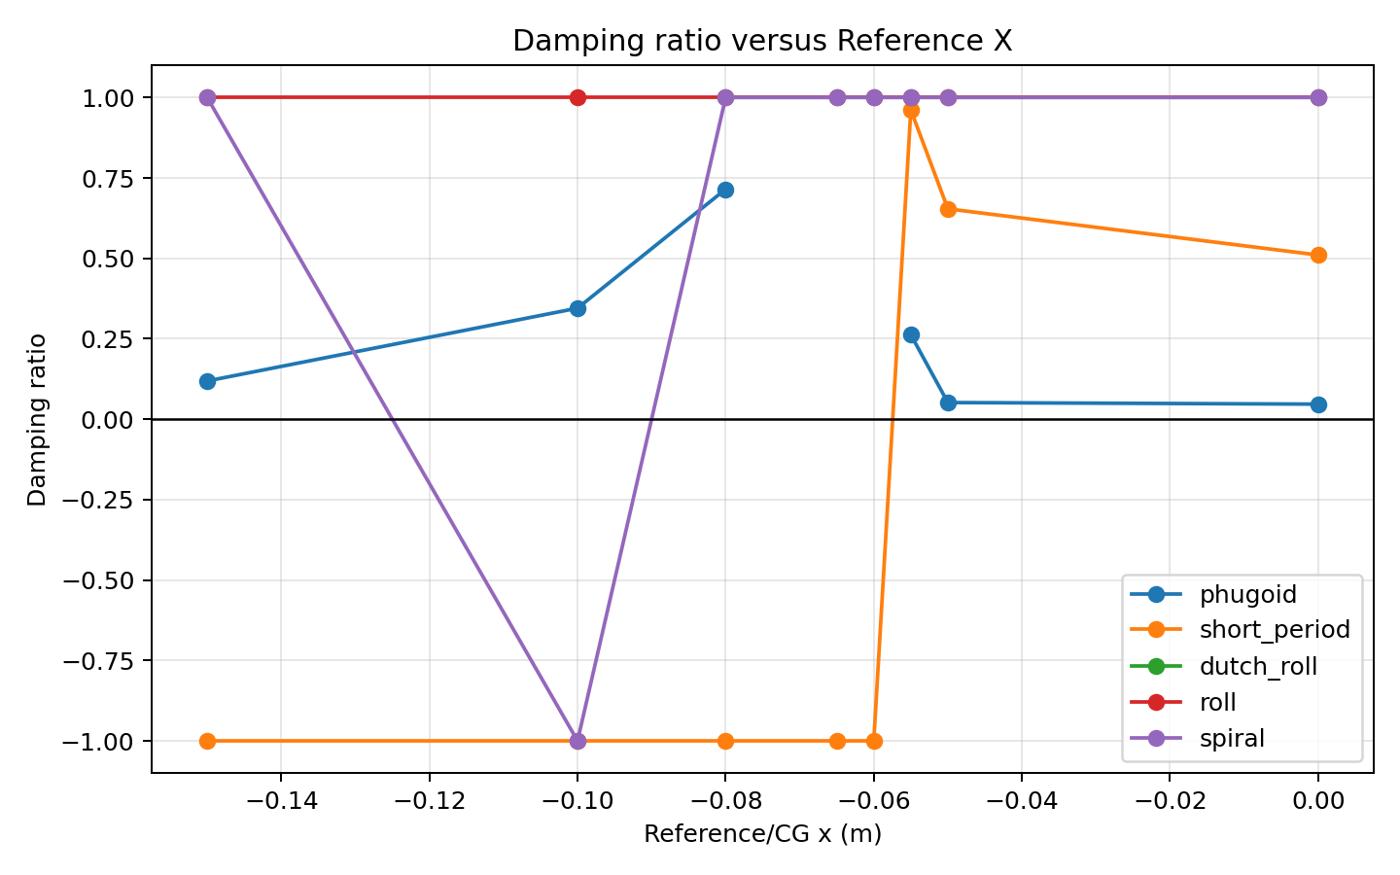
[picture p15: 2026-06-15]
docs/information-note/phase-1/Flight-Dynamics/0001-Preliminary-Fixed-Wing-Stability-Analysis/figures/damping_ratio_vs_reference_x.png

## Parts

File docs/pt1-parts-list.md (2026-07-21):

---
title: "Spearhead PT1 Electrical Parts List"
sidebar_label: "PT1 Parts List"
sidebar_position: 5
---

# Spearhead PT1 Electrical Parts List

**Doc ID:** SPH-E-003
**Author:** errrks
**Date:** June 17, 2026
**Status:** Ready for order review (next Spearhead call)
**Reference:** SPH-E-001 (electrical master, Rev 0.18) §4.16 cost baseline, §4.6 harness connection table

Procurement list for the PT1 order cycle, per the June 11 call. Focus areas requested by Alperen: voltage regulators, the tail CAN-to-PWM board, wiring and connectors, and items with long lead times.

**Sourcing rule:** buy in Turkey where stock exists (battery at motorobit, FC at rx-dynamic, servos at thkmodelucak, tail CAN board at Aykut Havacılık), then EU stock (Matek EU resellers, Holybro EU, Aeroboticshop NL) to keep customs simple, same as the MAD order with the ATR certificate. The Ainstein US-D1 is believed to be on hand in Turkey already, confirm before any US order.

---

## Priority 1 — order or request quote this week (long lead or gating)

| # | Item | Spec / model | Qty | Source candidate | Est. unit | Lead risk | Notes |
|---|---|---|---|---|---|---|---|
| 1 | [Flight controller](https://rx-dynamic.com/urun/holybro-pixhawk-6c-pm02/) | **Pixhawk 6C + PM02 V3** (full-size 6C, not Mini; analog PM02 V3 12S power module + cable set, **no GPS in this bundle**) | 1 | rx-dynamic (TR), ₺19,900 (~$600) | ~$600 | Medium | **D4 reopened and reclosed June 17: full 6C selected** (supersedes the June 11 6X). Its IO PWM still drives the flaperons (wing CAN node stays dropped), it has 5 UARTs (vs the Mini's 4) for the serial F9P, and its **two analog POWER ports** let the FCHUB vehicle V/I feed POWER2 directly (SPH-E-001 §4.13). No M9N in this bundle (a +M9NGPS 6C variant exists separately) — the primary GPS is the F9P (line 4b) |
| 2 | [CAN-to-PWM](https://www.aykuthavacilik.com/urun/ap-periph-can-node-can-l4-pwm) | **Matek CAN-L4-PWM** (AP_Periph, 9 PWM, JST-GH CAN, 3.5g) | 2 | Aykut Havacılık (TR), 2,060 TL (~$50) | $50 | Low (TR stock) | 1 install (tail, node 12, ruddervators) + 1 spare. The wing unit was dropped, the FC IO PWM drives the flaperons. Gates WP-E04 bench validation. Alternate at the same shop: CAN-L431 (5 PWM, 3 UART, I2C, dual parallel GH-4P CAN, 2,500 TL) if the L4-PWM sells out |
| 3 | [Tail servo regulator](https://www.aykuthavacilik.com/urun/power-module-12s-w-3xbec) | **Matek PM12S-3** (9–55V in w/ TVS. Vx selectable 5.25/6/8V at 15A cont / 25A peak, fixed 5.2V/4A, fixed 12V/4A, 1K:20K divider, 53g) | 1 | Aykut Havacılık (TR), 6,900 TL (~$170) | $170 | Low (TR stock) | **Tail only now (June 17):** Vx at 8V for the ruddervator Kingmax, fixed 5V for the tail adapter + Here4. Kept because it supplies both the 8V servo rail and the 5V logic rail in one TVS module. The forward unit is dropped — the wing rail moves to a robocombo buck (line 3b). **Price flag:** TR price ~4× Matek direct, accepted for customs simplicity |
| 3b | [Wing servo regulator](https://www.robocombo.com/dc-dc-8-60v-15a-ayarlanabilir-voltaj-dusurucu-modu-4017) | **robocombo DC-DC buck** (8–60V in, 15A adjustable) | 2 | robocombo (TR) | ~$15 | Low | 1 install (wing flaperon rail, HV input at the FCHUB pads, output set to **8.4V** for full Kingmax torque) + 1 spare. 8.4V is why this replaces the forward PM12S-3 (Vx caps at 8V). Lock the output pot, confirm true synchronous 15A with heatsink, scope for overshoot before connecting a servo |
| 4 | Tail GPS | **CubePilot Here4** (secondary GPS, CAN node 11) | 1 | Aeroboticshop (EU) | $300 | Medium | Secondary GPS. D1 closed June 17 with a serial F9P primary, so this stays a single Here4 (no matched pair) |
| 4b | Front GPS | **u-blox F9P** on a serial UART (GPS1), primary | 1 | Salvaged F9P on hand; antennas on hand | $0 | — | **D1 closed June 17:** salvaged F9P on serial (compass yaw), not DroneCAN. Uses the on-hand antennas. No purchase needed |
| 5 | Radar altimeter | **Ainstein US-D1** (UART + CAN, 100 Hz, 50 m, 110g, 5–13V) | 1 | **Believed on hand in Turkey, confirm unit + interface variant** | $0 if found | On-hand check | Selected June 11 over TF03-180 (radar tolerates prop wash dust). Only if the unit does not turn up: quote via Ainstein/distributor, then it becomes the longest lead item (~$280, High) |
| 6 | [Battery](https://www.motorobit.com/444v-12s-22000mah-15c-solid-state-lipo-batarya) | **motorobit 12S 22,000 mAh 15C solid-state LiPo** (44.4V, 3,709g, 190×78×126mm, QS8-S socket) | 1 | motorobit.com (TR) | TBD | Low (TR) | **D5 reopened/reclosed June 17:** single solid-state pack, supersedes the ProFuse 16Ah. 3,709g is ~113g lighter than the ProFuse so no CG penalty for the +6Ah. Send 190×78×126mm to Alperen for the forward bay. 15C = 330A continuous (covers the 320A peak, more sag than 60C). **QS8-S is anti-spark** (resolves the §4.3 connector question). Confirm price |
| 7 | [PDB](https://www.aykuthavacilik.com/urun/fchub-12s-v2-w-curr440a-5v-12v) | **Matek FCHUB-12S V2** (8–60V, 4×70A cont / 4×110A burst, 5V/5A + 12V/4A + 3.3V BECs, 440A sensor, VBat 1K:20K divider, PINIO-switchable 12V/2A pad) | 2 | Matek / EU reseller | $30 | Medium (confirm EU stock) | Promoted to P1 June 11: the only HV distribution board, it gates the entire HV path and every BEC rail, so a stock surprise stalls the build. 1 install + 1 spare. V2 divider closes the voltage sense question, the 12VSW pad can drive the HV kill contactor coil (D2) |

## Priority 2 — order with the main batch

| # | Item | Spec / model | Qty | Source candidate | Est. unit | Notes |
|---|---|---|---|---|---|---|
| 7 | [Control surface servos](https://www.thkmodelucak.com/urun/kingmax-servo-cls3015s-high-torque-8-4v-1958) | **Kingmax CLS3015S** (HV 6.0–8.4V, 35 kg·cm @ 8.4V, 0.15s/60°, metal gear, dual BB, waterproof, 80g, 25T) | 6 | thkmodelucak (TR), 3,950 TL each (~$110) | ~$110 | Medium | **Moved to final HV servos on PT1 (June 17), 5V test stage dropped.** 4 install (2 flaperon @ 8.4V robocombo + 2 ruddervator @ 8V PM12S-3) + 2 spares. One SKU for all surfaces. Note +100g aft tail mass for CG |
| 8 | CAN hub | CUAV CAN HUB or equivalent passive JST-GH splitter | 1 | CUAV / EU reseller | $15 | Fans CAN1 out to the four ESC stubs + nose + tail trunk |
| 9 | CAN terminators | 120Ω JST-GH plug | 2 | with hub order | $3 | FC end + last tail node, if not built into hub/devices |
| 10 | Battery connectors | QS8-S plug ×3 (mates the pack socket) + QS8-S ×2 (charge lead and bench adapter) | 1 lot | Amass / TR hobby | $20 | The pack's QS8-S is the ground safing disconnect and is anti-spark, so no AS150U adapter is needed and there is no mating spark regardless of the D2 kill choice |
| 11 | ESC junction connectors | XT90S pairs | 8 | Amass / EU reseller | $6 | Boom exceeds the 800mm factory lead (confirmed June 11), so all four ESC power leads are extended at the boom-fuselage junction with XT90S. On the tail-carrying boom this junction also breaks out the 18 AWG tail HV feed (H5). Qty covers 4 installs + spares/bench. Exact added length pending boom dimensions from Alperen |
| 12 | LV connectors | XT60 pairs ×4, XT30 pairs ×4 | 8 | Amass / EU reseller | $3 | XT60: power module leg. XT30: BEC inputs |
| 13 | Wing panel connectors | Molex Mini-Fit Jr 6-pin sets | 3 | Mouser/Digikey | $10 | 2 install + 1 spare, pending OQ-09 confirmation (cheap, order anyway) |
| 14 | HV wire | **8 AWG silicone, 1 m red + 1 m black** (battery harness) and **12 AWG silicone, 5 m red + 5 m black** (ESC lead extensions) | 1 lot | local / EU | $45 | 8 AWG for the battery QS8-S to FCHUB pads: 4 AWG does not fit the QS8 solder cups, and on this short run the connector (QS8 ~120A class), not the wire, is the thermal limit — monitor connector temp at worst-case hover (~124A). 12 AWG matches the AMPX factory leads and is the confirmed extension gauge throughout: MAD rates the factory 12 AWG at 80A and hover draw is only ~25–31A/motor, so no upsize is needed |
| 15 | LV + signal wire | 16 AWG (power module pigtail), 18 AWG (tail HV spur, 5 m), 20–26 AWG assortment, 24 AWG twisted pair (CAN, 5 m) | 1 lot | local / EU | $40 | Check the JST-GH cable stock first, the team already has many Pixhawk cables |
| 16 | Main harness parts | 8 AWG terminations, strain relief, cable lacing | 1 lot | local | $15 | Series link dropped, single 12S pack selected |
| 17 | LV kill switch | Illuminated rocker or key switch, 10A | 1 | local | $15 | Independent of the HV kill decision (D2), order now |
| 18 | LED system | WS2812B strip + 22 AWG feed wire | 1 lot | local / EU | $20 | E-REQ-11. Own 5V feed, off the peripheral rail |
| 19 | Pitot transducer backup | Holybro / Matek I2C DLVR airspeed sensor | 1 | EU reseller | $30 | Backup in case the drawer pitot (OQ-06) has no usable transducer |
| 20 | Cell checker | Plug-in balance checker/alarm | 2 | local | $5 | Ground checks only, the dumb pack has no BMS |
| 21 | Consumables | Solder-seal sleeve assortment (LV sizes), dual wall adhesive heat-shrink assortment, regular heat-shrink assortment, braided sleeve, zip ties, mounting hardware, threadlock | 1 lot | local | $50 | Solder sleeves are for LV and signal splices. HV splices get a soldered lap joint under dual wall adhesive heat-shrink |
| 22 | 12 AWG splice sleeves | Solder-seal sleeves sized for 12 AWG (ESC lead extensions) | 12 | local / EU | $10 | On the 80A path prefer a soldered lap joint + dual wall adhesive heat-shrink, use sleeves only where iron access is awkward, and pull-test every joint |
| 23 | Motor phase bullets | 5mm gold bullet sets (mate the MAD phase leads) | 12 | local / EU | $2 | Only where phase leads get connectorized instead of soldered direct |
| 24 | JST kits | Genuine **JST-GH 1.25mm** kit with pre-crimped pigtails (CAN, Pixhawk peripherals) + **JST-PH 2.0mm** kit | 2 kits | Mouser/Digikey | $25 | Generic "1.25mm Micro JST / PicoBlade" is not GH and will not latch, buy actual GH. The FCHUB V2's JST-SH 1.0mm cable ships with the board |
| 25 | Servo leads | JR 3-pin extensions and pre-crimped pigtails, assorted lengths | 1 lot | local TR hobby | $15 | Tail bay servo runs (H15/H16), wing root runs, and bench |
| 26 | [RC link](https://www.radiolink.com/at9spro) | **Radiolink AT9S Pro** TX + **R9DS** receiver (10-ch, 2.4 GHz, SBUS out) | 1 set | Radiolink / TR or EU hobby | ~$130 | **RC side closed June 18 (D3).** SBUS into the 6C RC-IN port (H18). This is the transmitter the pilots will use. Confirm channel map + failsafe in WP-E08 |
| 27 | Telemetry radio | **Holybro SiK Radio V3** (915 MHz, 100 mW, MAVLink 2.0) | 1 | Borrowed from STORK for first flight | $0 | First-flight fallback (D3, June 18), TELEM1 (H17). Range-limited; long-term Spearhead unit (RFD900x-class) still TBD, Zeynep + Alperen to research |

### Battery interface build (how the PM02 V3 pairs to the battery)

No Y-cable. The FCHUB-12S battery pads are the split point:

1. Battery main connector (pack default) → 8 AWG red/black, ~0.4 m → solder to the FCHUB B+ / B− pads. The HV kill (D2) goes inline in this run.
2. At the same pads, solder a 16 AWG pigtail ending in an XT60 female → PM02 V3 XT60 input. The PM02 V3 sees pack voltage at the same electrical node a Y-splitter would give it.
3. PM02 V3 XT60 output: unused, insulate it. Its 6-pin CLIK-Mate cable goes to Pixhawk 6C POWER1 (5.2V analog, BATT2).
4. **Vehicle V/I:** a separate 4-wire CLIK-Mate from the FCHUB 440A sensor + VBat divider goes to 6C **POWER2** (Curr→CURRENT2, V→VOLTAGE2, GND→GND, POWER2 5V pins open). FCHUB = BATT1 (vehicle current + SoC), enabled by the 6C's second analog port. No cutting the PM02 harness. See SPH-E-001 §4.13.

Fallback if two wire sets crowd the pads: solder both the 8 AWG main and the 16 AWG branch into the main connector's solder cups together (8 AWG + 16 AWG fit a 6mm cup), which moves the split into the connector barrel. Electrically identical. Pick one approach, not both.

## Priority 3 — blocked on a decision (do not order yet)

| ID | Decision | Options on the table | Owner | Needed by |
|---|---|---|---|---|
| D1 | ~~Nose (primary) GPS, OQ-12~~ | **Closed June 17: u-blox F9P on a serial UART (GPS1)**, compass yaw, on-hand antennas (line 4b). Mixed serial-F9P + CAN-Here4 means no moving-baseline GPS yaw | Team call | Closed |
| D2 | ~~HV kill implementation, OQ-05~~ | **Closed June 17: no hardware HV kill for PT1.** Software E-stop (ArduPilot motor emergency stop on an RC switch, AMPX 2 s CAN watchdog backstop) + QS8-S anti-spark unplug for ground safing. Recorded §9.3 deviation (E-REQ-02). LV kill retained. Rationale: no clean contactor placement for PT1 without added mass, and the QS8-S anti-spark already manages connection inrush. Contactor/MOSFET analysis kept as record in SPH-E-001 §4.3; full HV kill returns for the final product | Erick + Alperen | Closed |
| D3 | RC link + telemetry radio, OQ-04 | **RC side closed June 18: Radiolink AT9S Pro + R9DS receiver (SBUS)** (lines 26-27 below). Telemetry side: first flight borrows STORK's Holybro SiK V3; the long-term Spearhead telemetry radio (RFD900x-class) is still open | Team call | RC closed; long-term telemetry before Phase 3 |
| D4 | FC selection | **Reclosed June 17: full-size Pixhawk 6C + PM02 V3** (line 1), supersedes the June 11 6X. IO PWM still drives the flaperons, 5 UARTs fit the serial F9P, and two analog POWER ports carry the FCHUB V/I. Sourced from rx-dynamic TR | Alperen (sourcing) | Closed |
| D5 | Battery format | **Closed June 17: single motorobit 12S 22Ah 15C solid-state pack** (line 6), 3,709g, 190×78×126mm, QS8-S anti-spark socket. Supersedes the June 11 ProFuse. Only price left to confirm | — | Closed |

## Ordered — in transit (MAD Motor Poland, no action except customs paperwork)

Ordered ~May 1, 2026 with the ATR certificate requested for zero-tax EU-to-Turkey import. Status June 11: MAD sent the purchaser/customs document, Alperen must print, sign, and return it. Listed here for completeness, full specs in SPH-E-001 §4.5.

| Item | Spec / model | Qty | Unit | Total | Notes |
|---|---|---|---|---|---|
| [VTOL motors](https://store.mad-motor.com/products/v8013-pro-ipe-feathering-propeller-autocenter-evtol-drone-motor) | **MAD V8013 PRO IPE 150KV** (591g, 15 kgf max thrust, prop autocenter indexing, 12S) | 6 | ~$185 | ~$1,110 | 4 install + 2 spares |
| [ESCs](https://store.mad-motor.com/products/ampx-80a-5-14s-drone-esc) | **MAD AMPX 80A V2 DroneCAN** (5–14S, IP67, CAN telemetry, 12AWG/800mm power leads) | 6 | $60 | $360 | 4 install + 2 spares. CAN nodes 1–4 |
| [Propellers](https://store.mad-motor.com/products/fluxer-pro-26-7-8inch-matt-carbon-fiber-propeller-for-the-long-range-flight-time-professional-hexacopter) | **MAD FLUXER PRO 26×7.8 MATT** carbon, fixed (69g/blade, Ø10mm bore, Ø20mm M3×4 hub) | 6 pairs | $193.90 | ~$1,163 + $60 ship | 12 blades (6 CW + 6 CCW), 4 installed, spares absorb early breakage. Ultralight variant deferred to ~Aug 2026 |
| **Subtotal (ordered)** | | | | **~$2,633** | |

## On hand — no order

| Item | Status |
|---|---|
| GPS antennas | On hand per June 11 call |
| Pixhawk / JST-GH cable assortment | On hand, top up only after stock check (line 15) |
| Pitot tube | In Alperen's drawer, model and transducer TBD (OQ-06) |

---

## Totals (estimate, decisions pending)

| Block | Est. |
|---|---|
| Priority 1 (6C + PM02 V3 set ~$600, single Here4, F9P TBD, motorobit pack TBD, 1× PM12S-3, 2× robocombo buck, 2× CAN-L4-PWM, 2× FCHUB-12S V2, US-D1 on hand) | ~$1,300 + battery/F9P TBD |
| Priority 2 (incl. 6× Kingmax CLS3015S ~$660, Radiolink AT9S Pro RC set ~$130, SiK V3 telemetry borrowed $0) | ~$1,130 |
| Decision items (D2 contactor route, if chosen) | ~$160 |
| If the US-D1 does not turn up in Turkey | +$280 |
| **PT1 order cycle total** | **~$2,430–2,880 + battery + F9P** (incl. ~$130 Radiolink RC set; SiK V3 telemetry borrowed) |
| Already ordered and in transit (MAD propulsion set, memo only) | ~$2,633 |

Cost baseline and per-phase totals stay in SPH-E-001 §4.16. Cable-level connection detail (what plugs into what, AWG, lengths) is SPH-E-001 §4.6, harness connection table.

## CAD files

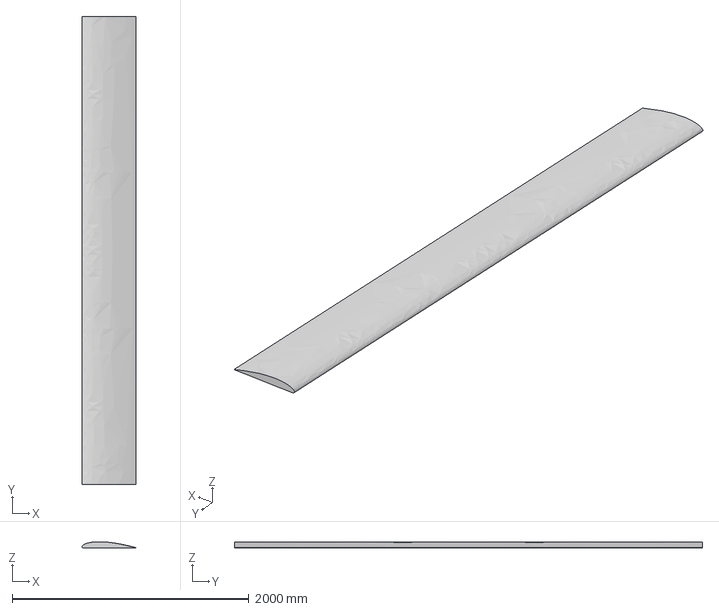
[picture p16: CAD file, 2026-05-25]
docs/information-note/phase-1/Aerodynamics/0001-Preliminary-Design/assets/main_wing.step
456.9 x 3950.0 x 54.6 mm

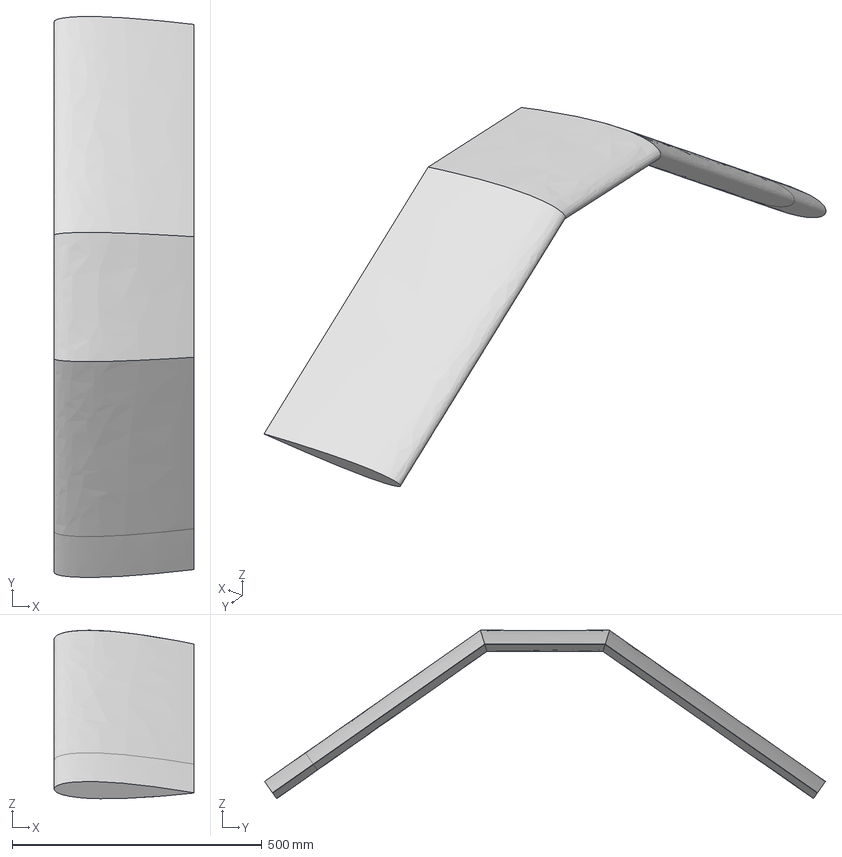
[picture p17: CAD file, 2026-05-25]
docs/information-note/phase-1/Aerodynamics/0001-Preliminary-Design/assets/tail_wing.step
279.8 x 1123.8 x 337.6 mm

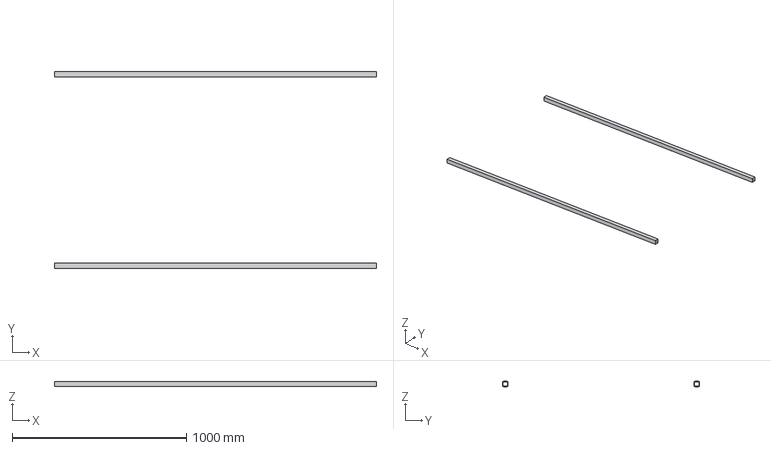
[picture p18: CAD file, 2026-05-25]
docs/information-note/phase-1/Aerodynamics/0001-Preliminary-Design/assets/longitudinal_booms.step
1850.0 x 1130.0 x 30.0 mm

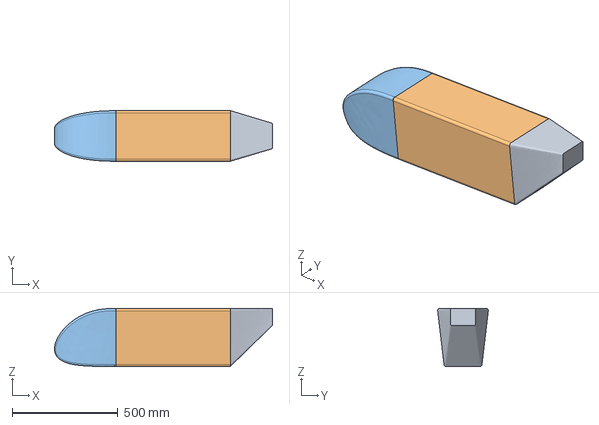
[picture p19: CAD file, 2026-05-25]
docs/information-note/phase-1/Aerodynamics/0001-Preliminary-Design/assets/fuselage.step
1032.2 x 240.1 x 275.0 mm

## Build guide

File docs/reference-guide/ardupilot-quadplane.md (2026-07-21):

---
title: "ArduPilot QuadPlane Reference"
sidebar_label: "ArduPilot QuadPlane"
sidebar_position: 1
---

# ArduPilot QuadPlane Reference for Project Spearhead

*Extracted and filtered from the official ArduPilot Plane documentation. Tailsitter, tilt-rotor, and other non-applicable sections omitted. Focused on a Quad-X pusher IC engine configuration at ~25 kg MTOW.*

---

## 1. Enabling QuadPlane

QuadPlane is a mode within the standard **Plane** firmware — there is no separate firmware. Set `Q_ENABLE = 1` and reboot. All QuadPlane parameters use the `Q_` prefix. After enabling, refresh the parameter list to see the full set.

---

## 2. Frame Setup

### Frame Class & Type

| Parameter | Value | Meaning |
|---|---|---|
| `Q_FRAME_CLASS` | 1 | Quad (4 VTOL motors) |
| `Q_FRAME_TYPE` | 1 | X frame layout |

For Spearhead's quad-X, use `Q_FRAME_CLASS = 1`, `Q_FRAME_TYPE = 1`.

**H vs X mixing:** If the airframe is perfectly rigid the difference is negligible. However, quadplane structures are often less rigid than traditional multirotors and torsional effects must be considered. When yaw input results in most weight being supported by a diagonal motor pair, the fuselage or wing may twist and distort thrust vectors. Choose the mixing scheme (X or H) that ensures any induced twist *complements* the desired yaw. For motors mounted on arms extending fore/aft aligned with the wing chord, X mixing is usually correct.

### Motor Ordering (Quad-X Default)

| Output | Motor | Position | Rotation |
|---|---|---|---|
| 5 | Motor 1 | Front right | Counter-clockwise |
| 6 | Motor 2 | Rear left | Counter-clockwise |
| 7 | Motor 3 | Front left | Clockwise |
| 8 | Motor 4 | Rear right | Clockwise |

Rule of thumb: "motors turn in towards the fuselage" for X frame.

Outputs 1–4 are reserved for conventional plane control surfaces (aileron, elevator, rudder, throttle) by default when `Q_ENABLE` is set.

### Remapping Outputs

If you need motors on different channels, set `SERVOn_FUNCTION` values: Motor 1 = 33, Motor 2 = 34, Motor 3 = 35, Motor 4 = 36. Only do this for non-standard ordering; the defaults auto-configure on boot.

---

## 3. Building Guidance

### Key Design Principles

- **Frame strength:** Must carry VTOL motors, power system, and payload without flex. Minimum wing/frame/mount twist is critical so motors provide thrust vertically at all times.
- **Motor clearance:** Complete clearance above and below the full disk area of each VTOL motor for full aerodynamic thrust.
- **Robust mounts:** The VTOL motor mounting system must handle the vibration and loads of hover flight at full MTOW.
- **Drag minimization:** Minimize aerodynamic drag from VTOL motors, arms, and mounting hardware for efficient cruise.
- **Motor alignment is critical:** A few degrees of misalignment can eliminate yaw authority in one or both directions. Check on the bench by blocking the vehicle level and measuring prop-tip-to-table distances in fore-aft and side-to-side orientations. The arc-sine of tip-end differences divided by prop diameter gives the tilt angle. Even 1–2° matters for yaw.
- **Intentional yaw tilt:** You can *increase* yaw authority by purposely tilting one or both pairs of adjacent rotating motors 1–2° in the direction of their torque (outward for X frame).
- **Use eCalc** to choose motors, ESCs, batteries, and propellers. Motor power-to-weight ratios vary enormously.

### Wing Downforce in Hover

The VTOL motors must provide thrust not just for total airframe weight, but also for the additional downforce on the wings when hovering in a horizontal stance. This is a significant consideration at 25 kg MTOW with a 3.95 m span wing.

### IC Engine for Cruise — Range Advantage

A QuadPlane with VTOL takeoff can actually have *greater* range than the same airframe with conventional launch, because:

1. No need for high-thrust takeoff capability on the forward motor — allows optimizing the pusher prop/engine for cruise efficiency (larger prop, geared motor, etc.)
2. No stall-speed acceleration requirement at launch — can carry more fuel/battery
3. IC engine cruise provides dramatically better endurance than electric

To maximize this advantage, do very rapid VTOL takeoffs and landings to minimize battery consumption in hover.

---

## 4. Critical Parameters

### Core QuadPlane Parameters

| Parameter | Purpose | Spearhead Notes |
|---|---|---|
| `Q_ENABLE` | Enable QuadPlane (1) | Must set and reboot |
| `Q_FRAME_CLASS` | Motor arrangement | 1 (Quad) |
| `Q_FRAME_TYPE` | Motor layout | 1 (X) |
| `Q_M_PWM_MIN` / `Q_M_PWM_MAX` | PWM range for VTOL ESCs | Set to match your ESC protocol |
| `Q_M_SPIN_ARM` | Motor output when armed in quad mode | Important for idle behavior |
| `Q_M_THST_HOVER` | Throttle % for hover at mid-stick | Calibrate so QSTABILIZE hovers at mid-stick ±6% |
| `Q_M_HOVER_LEARN` | Auto-learn hover throttle | Enable in QLOITER/QHOVER |
| `Q_A_RAT_RLL_P` | Roll rate P gain | Default 0.25 — QuadPlanes often need significantly higher |
| `Q_A_RAT_PIT_P` | Pitch rate P gain | Default 0.25 — often needs to be higher |
| `Q_A_ANGLE_MAX` | Max lean angle in VTOL modes (cdeg) | Controls pitch/roll limits |
| `Q_TRIM_PITCH` | VTOL pitch trim offset | Corrects backward drift from fixed-wing level trim |
| `SCHED_LOOP_RATE` | Scheduler loop rate | Default 300 Hz for QuadPlane — do not raise for 25 kg vehicle |
| `ARMING_RUDDER` | Rudder arming | Set to 2 for rudder disarm |

### Transition Parameters

| Parameter | Purpose | Spearhead Notes |
|---|---|---|
| `AIRSPEED_MIN` | Minimum airspeed / transition complete speed | VTOL motors cut after reaching this |
| `Q_TRANSITION_MS` | Time to ramp down VTOL motors after reaching AIRSPEED_MIN | Default 5000 ms (5 sec) |
| `Q_TRANS_FAIL` | Transition timeout (sec) | 0 = disabled. If set, transition aborts if AIRSPEED_MIN not reached |
| `Q_TRANS_FAIL_ACT` | Action on transition failure | What happens when Q_TRANS_FAIL triggers |
| `Q_BACKTRANS_MS` | Back-transition pitch limit ramp time | Controls pitch-up rate when transitioning FW→VTOL |
| `Q_TRANS_DECEL` | Deceleration for approach calculations | Used by RTL/AUTO to judge when to start VTOL transition |
| `TKOFF_THR_MIN` | Minimum throttle during transition | Applied during VTOL→FW transition |

### Assist Parameters

| Parameter | Purpose | Spearhead Notes |
|---|---|---|
| `Q_ASSIST_SPEED` | Airspeed below which VTOL motors assist | Set above stall speed. Use -1 to disable (suppresses pre-arm warning) |
| `Q_ASSIST_ANGLE` | Attitude error (deg) above which assist activates | Backup trigger even if above Q_ASSIST_SPEED |
| `Q_ASSIST_ALT` | AGL altitude below which assist activates | Uses rangefinder/terrain data |
| `Q_ASSIST_DELAY` | Delay before assist activates after threshold | Prevents false triggers |

**Important:** If not using an airspeed sensor, the synthetic airspeed estimate can be very inaccurate. Consider carefully whether to enable assist without a real airspeed sensor.

### RTL & Failsafe Parameters

| Parameter | Purpose |
|---|---|
| `Q_RTL_MODE` | Controls hybrid RTL behavior (0–3) |
| `Q_RTL_ALT` | Altitude target for VTOL portion of hybrid RTL |
| `Q_OPTIONS` | Bitmask for many behavioral tweaks (see below) |
| `FS_SHORT_ACTN` / `FS_LONG_ACTN` | Plane failsafe actions |
| `RTL_RADIUS` | Distance at which to transition from FW to VTOL in RTL |
| `RTL_ALTITUDE` | Altitude for fixed-wing return leg |

### Weathervaning Parameters

| Parameter | Purpose |
|---|---|
| `Q_WVANE_ENABLE` | Enable weathervaning (1 = nose into wind) |
| `Q_WVANE_GAIN` | Lean angle → yaw rate conversion |
| `Q_WVANE_ANG_MIN` | Minimum lean angle before weathervaning activates (default 1°) |
| `Q_FWD_THR_GAIN` | Use forward motor to help hold position in wind (v4.5+) |
| `Q_FWD_THR_USE` | Controls when forward thrust assist is used |

### Forward Motor in VTOL

| Parameter | Purpose |
|---|---|
| `Q_VFWD_GAIN` | (Legacy) Use forward motor for position hold in wind |
| `Q_FWD_THR_GAIN` | (v4.5+, preferred) Forward motor position hold |
| `Q_FWD_MANTHR_MAX` | Max throttle for manual forward motor channel |
| `RCx_OPTION = 209` | Assigns an RC channel for manual forward motor in VTOL modes |

---

## 5. Q_OPTIONS Bitmask (Key Bits for Spearhead)

| Bit | Value | Effect |
|-----|---|---|
| 0 | +1 | Keep wings level during VTOL→FW transition (no climbing with VTOL motors) |
| 1 | +2 | Use FW takeoff for TAKEOFF command (instead of VTOL) |
| 2 | +4 | Use FW landing for LAND command |
| 3 | +8 | Respect takeoff frame altitude |
| 4 | +16 | Use fixed-wing approach for VTOL_LAND |
| 5 | +32 | Use QRTL on RC failsafe in VTOL modes |
| 7 | +128 | Force assist active at all times |
| 14 | +16384 | Use only Q_A_ANGLE_MAX for VTOL angle limits (ignore FW limits) |
| 15 | +32768 | Allow throttle descent control during VTOL auto-land |
| 16 | +65536 | Disable FW approach phase in QRTL (pure VTOL return) |
| 17 | +131072 | Allow horizontal repositioning during VTOL auto-land |
| 20 | +1048576 | Use RTL (instead of QRTL) on failsafe |

---

## 6. Flight Modes

### VTOL Modes (Quad Motor Active)

| Mode | Description | Spearhead Use |
|---|---|---|
| **QSTABILIZE** | Rate-stabilized, no altitude hold. Throttle directly controls VTOL thrust. | Basic hover testing |
| **QHOVER** | Altitude hold at mid-stick. Throttle controls climb/descent rate. | Hover testing, tuning |
| **QLOITER** | Position + altitude hold. GPS required. | Primary hover mode for ops |
| **QLAND** | Automated vertical landing | Emergency / mission end |
| **QRTL** | Return to launch in VTOL (or hybrid, depending on Q_RTL_MODE) | Failsafe / return |
| **QAUTOTUNE** | Automatic PID tuning in VTOL | Essential for initial tuning |

### Fixed Wing Modes (Recommended for QuadPlane)

| Mode | Description |
|---|---|
| **FBWA** | Stabilized FW flight, pilot controls attitude. **Recommended over STABILIZE** for QuadPlanes. |
| **FBWB** | Stabilized with altitude hold via pitch stick |
| **CRUISE** | GPS-stabilized cruise with altitude hold |
| **AUTO** | Autonomous mission following |
| **RTL** | Return to launch (behavior depends on Q_RTL_MODE) |
| **GUIDED** | GCS-commanded waypoints |

### Modes to AVOID in QuadPlane

**STABILIZE, ACRO, TRAINING, MANUAL** — In these modes the quad motors are disabled (except MANUAL which is intentional). The stick input is insufficient for the autopilot to determine desired attitude/climb rate for VTOL assistance. Use **FBWA** instead of STABILIZE. MANUAL immediately cuts VTOL motors — risk of stall if insufficient airspeed.

---

## 7. Transitions

### VTOL → Fixed Wing

1. Switch to any FW mode (FBWA recommended for manual transitions).
2. VTOL motors continue providing lift and stability during "transition airspeed wait" phase.
3. Forward motor (IC engine) spools up; throttle stick controls forward thrust in FBWA.
4. Elevator input during transition controls VTOL climb/descent rate (unless `Q_OPTIONS` bit 0 is set).
5. Once `AIRSPEED_MIN` is reached, VTOL motor contribution ramps down over `Q_TRANSITION_MS` (default 5 sec).
6. After ramp-down, aircraft flies as pure fixed-wing.
7. If `Q_TRANS_FAIL` is set and AIRSPEED_MIN is not reached in time, the transition aborts per `Q_TRANS_FAIL_ACT`.

**Battery warning:** During transition, all motors (VTOL + pusher) can run at very high levels simultaneously. Battery sag below 3.0V/cell (LiPo) is possible and can cause crashes. This is especially relevant for high-capacity, low-C-rating batteries. Monitor voltage during first manual transitions. Solutions: higher C-rating battery, separate VTOL and FW batteries, or use `BATT_WATT_MAX` to limit current draw.

### Fixed Wing → VTOL

1. Switch to any VTOL mode (QHOVER, QLOITER, etc.).
2. Forward motor immediately stops.
3. Control surfaces continue providing stability as the aircraft decelerates.
4. VTOL motors engage and manage attitude/altitude as speed drops.
5. When transitioning to position-hold modes (QLOITER), pitch is initially limited to 0° and relaxes to `Q_A_ANGLE_MAX` over `Q_BACKTRANS_MS` to prevent violent pitch-up and altitude gain.
6. Transitioning at high speed to QLOITER will result in nose-up pitching and altitude gain — plan accordingly.

### Typical First Flight Sequence

1. VTOL takeoff in **QLOITER** or **QHOVER**
2. Switch to **FBWA**, advance throttle above 50%, fly fixed wing
3. Switch to **QHOVER** to return to quad mode, reduce throttle to 50% for hover

---

## 8. Assisted Fixed-Wing Flight

When `Q_ASSIST_SPEED` is set to a positive value (above stall speed), the VTOL motors will automatically engage to provide lift and stability whenever:

- Airspeed drops below `Q_ASSIST_SPEED`, OR
- Attitude error exceeds `Q_ASSIST_ANGLE`, OR
- Altitude drops below `Q_ASSIST_ALT` (AGL)

Assist activates after `Q_ASSIST_DELAY` seconds. It works in all FW modes except MANUAL and ACRO.

**For initial flights**, keep `Q_ASSIST_SPEED` disabled to test basic FW functionality. Enable it later, set above stall speed.

An RC switch (`RCx_OPTION = 82`) can override assist: LOW = force off, HIGH = force on.

---

## 9. Weathervaning & Wind Hold

### Active Weathervaning

For a large-wing 25 kg aircraft, wind presents a major challenge in VTOL hover. Weathervaning automatically yaws the nose into the wind during position-controlled VTOL modes (QLOITER, QLAND, QRTL, AUTO VTOL phases — NOT QSTABILIZE or QHOVER).

Set `Q_WVANE_ENABLE = 1` (nose into wind). Start with `Q_WVANE_GAIN = 1`. If yaw oscillates, reduce gain.

**Critical:** `Q_TRIM_PITCH` must be properly set before enabling pitch-driven weathervaning (`Q_WVANE_OPTIONS` bit 0). Without correct pitch trim, you'll get continuous unwanted yawing.

QuadPlanes rarely have the same yaw authority as multirotors due to greater mass and wing area. In significant wind, expect to only be able to face into the wind.

### Forward Motor Wind Hold (v4.5+)

Set `Q_FWD_THR_GAIN` and `Q_FWD_THR_USE` to use the pusher engine to help hold position in wind during VTOL modes. This dramatically reduces the lean angle needed and the load on VTOL motors. This is the preferred method over the legacy `Q_VFWD_GAIN`.

---

## 10. Return to Launch (RTL)

### Q_RTL_MODE Options

| Mode | Behavior |
|---|---|
| **0** | Pure FW RTL — fly back and loiter as fixed wing. VTOL motors only engage if Q_ASSIST triggers. |
| **1** | Hybrid — FW return, switch to VTOL at `RTL_RADIUS`, descend to `Q_RTL_ALT`, land vertically. |
| **2** | FW return → loiter to `Q_RTL_ALT` at `Q_FW_LND_APR_RAD` → face wind → QRTL and land. |
| **3** | FW return → approach → airbrake → VTOL transition → land. Most automated option. Also used by default for QRTL mode. |

**For Spearhead:** `Q_RTL_MODE = 3` is recommended — it provides a complete automated FW approach and VTOL landing from any distance, with airbraking to reduce speed before VTOL transition.

### QRTL Mode

By default, QRTL behaves the same as RTL with `Q_RTL_MODE = 3`. If `Q_OPTIONS` bit 16 is set, QRTL becomes pure VTOL return (no FW approach) — only use this when close to home.

### RC Failsafe in VTOL Modes

Regardless of `FS_SHORT_ACTN`/`FS_LONG_ACTN`, RC failsafe during VTOL flight triggers QLAND, QRTL, or RTL depending on `Q_OPTIONS` bits 5 and 20. If failsafe occurs during VTOL takeoff, it immediately switches to QLAND.

---

## 11. AUTO Missions

### VTOL Takeoff (NAV_VTOL_TAKEOFF)

- Set altitude parameter to desired height above takeoff point
- Aircraft climbs at `Q_WP_SPD_UP` until altitude reached
- Then proceeds to next waypoint, transitioning to FW as needed
- Latitude/longitude of the command are ignored
- Set `Q_NAVALT_MIN` to a non-zero value to prevent GPS-noise-induced roll/pitch during initial climb (forces level until that altitude)

### VTOL Landing (NAV_VTOL_LAND)

**Firmware 4.1+:** By default, NAV_VTOL_LAND remains in FW mode, flies to near the landing point, executes an airbrake maneuver, transitions to VTOL, navigates precisely to the landing point, and descends. This allows placing the land point at any distance from the last waypoint.

For a mission-end landing, place the last waypoint at ~20 m AGL before the NAV_VTOL_LAND command. For small QuadPlanes, 60–80 m separation is good; for Spearhead's size and speed, plan for a larger distance.

### Mixing FW and VTOL in Missions

Use `DO_VTOL_TRANSITION` with parameter 3 (VTOL mode) or 4 (FW mode) to switch mid-mission. Example: VTOL takeoff → FW cruise to survey area → transition to VTOL for hover photography → FW return → VTOL land.

### Hovering in Missions

Set `Q_GUIDED_MODE = 1` to make LOITER commands execute as VTOL hover instead of FW circle. This allows pausing at waypoints for photography while flying the rest of the mission as FW.

### GUIDED Mode

With `Q_GUIDED_MODE = 1`, GUIDED mode destination hold is done as VTOL hover. The approach is FW; transition to VTOL begins at `WP_LOITER_RAD` (80 m is a good starting value).

---

## 12. Setup Tips (Spearhead-Specific)

### Level Calibration

Perform accelerometer "level" calibration with the aircraft in its normal **cruise attitude** (i.e., with the wing at its cruise angle of attack, not flat). This sets the AHRS reference for fixed-wing flight.

For the VTOL motors, it's ideal to mechanically tilt each motor to be truly vertical when the airframe is in this cruise attitude. This typically requires 3–5° of forward tilt on the motor mounts. Benefits:
- Eliminates the need for `Q_TRIM_PITCH` correction
- Wings generate lift during hover in wind, reducing VTOL motor load
- Prevents sudden pitch changes during FW→VTOL transitions

If using 3D-printed motor mounts, building in this tilt is easy.

### Hover Throttle Calibration

If the aircraft doesn't hover at mid-stick (±6%) in QSTABILIZE, adjust `Q_M_THST_HOVER` to the correct percentage. Enable `Q_M_HOVER_LEARN` in QLOITER/QHOVER for automatic learning.

### Large Vehicle Considerations

- Calibrate the accelerometer on the bench before installation (Large Vehicle MagCal recommended)
- At 25 kg MTOW, the higher inertia means no benefit from raising `SCHED_LOOP_RATE` above 300 Hz
- The pitch and roll limits in VTOL modes are the lesser of `Q_A_ANGLE_MAX` or the FW limits (`PTCH_LIM_MAX_DEG`, `PTCH_LIM_MIN_DEG`, `ROLL_LIMIT_DEG`)
- `Q_BCK_PIT_LIM` limits backward pitch when airspeed is at AIRSPEED_MIN to prevent structural loads during deceleration

### QLOITER Ground Behavior

Landing detection in QLOITER is less sophisticated than Copter. If GPS shows movement while on the ground, the aircraft may try to tip over attempting to hold position. Disarm promptly after landing, or use QLAND for automated landing.

---

## 13. Simulation (SITL)

Before flying Spearhead, test all mission profiles, transitions, and failsafe behaviors in SITL:

```bash
sim_vehicle.py -j4 -v Plane -f quadplane --console --map
```

Add `-w` to reset parameters to QuadPlane defaults. Load a sample VTOL mission:

```
wp load ../Tools/autotest/Generic-Missions/KSFO-VTOL.txt
```

Use a USB transmitter adapter with the joystick module to practice QuadPlane controls.

---

## 14. Pre-Flight Checklist (Derived from ArduPilot Docs)

1. **Motor alignment verified** on bench (prop-tip distance method)
2. **Motor rotation direction confirmed** (X frame: inward toward fuselage)
3. **VTOL motor spin-up tested** in QSTABILIZE while secured
4. **Hover throttle calibrated** (`Q_M_THST_HOVER` or `Q_M_HOVER_LEARN`)
5. **Q_TRIM_PITCH set** (or motors mechanically tilted) — no backward drift in hover
6. **Q_ASSIST_SPEED set** above stall speed (or -1 for initial flights)
7. **Transition timeout** (`Q_TRANS_FAIL`) configured for safety
8. **RTL mode configured** (`Q_RTL_MODE`, `RTL_RADIUS`, `Q_RTL_ALT`)
9. **Failsafe actions verified** in SITL
10. **Airspeed sensor calibrated** (strongly recommended for transition accuracy)
11. **Battery voltage monitored** during first manual transition — check for excessive sag
12. **Weathervaning configured** if operating in wind

---

## 15. Key Documentation Links

| Topic | URL |
|---|-----|
| QuadPlane Overview | https://ardupilot.org/plane/docs/quadplane-overview.html |
| Building | https://ardupilot.org/plane/docs/quadplane-building.html |
| Frame Setup | https://ardupilot.org/plane/docs/quadplane-frame-setup.html |
| Flying | https://ardupilot.org/plane/docs/quadplane-flying.html |
| Transitions | https://ardupilot.org/plane/docs/quadplane-transitions.html |
| Assisted Flight | https://ardupilot.org/plane/docs/assisted_fixed_wing_flight.html |
| RTL | https://ardupilot.org/plane/docs/quadplane_rtl.html |
| Parameters | https://ardupilot.org/plane/docs/quadplane-parameters.html |
| Flight Modes | https://ardupilot.org/plane/docs/quadplane-flight-modes.html |
| Weathervaning | https://ardupilot.org/plane/docs/quadplane-weathervaning.html |
| AUTO Missions | https://ardupilot.org/plane/docs/quadplane-auto-mode.html |
| Tips | https://ardupilot.org/plane/docs/quadplane-tips.html |
| Simulation | https://ardupilot.org/plane/docs/quadplane-simulation.html |
| ESC Calibration | https://ardupilot.org/plane/docs/quadplane-esc-calibration.html |
| Porter OctoQuadPlane Build | https://diydrones.com/profiles/blogs/building-flying-and-not-crashing-a-large-octaquadplane |
| Mozzie Build | http://mozzie.readthedocs.io/ |

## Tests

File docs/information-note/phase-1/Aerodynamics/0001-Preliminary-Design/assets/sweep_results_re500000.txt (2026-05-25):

Airfoil Sweep Results - Re = 500,000
============================================================

Top 30 Candidates

===============================================================================================================================
  Airfoil Sweep - Wing Sizing Comparison
  Ranked by composite score (40% wing area, 40% drag, 10% tail, 10% stall safety)
===============================================================================================================================
  #    Wing Airfoil    | Tail Airfoil             |  S_wing  Span Chord t_abs i_tail  D_tot   L/D  CLmax M_stall    Stall Score
                       |                          |    (m2)   (m)   (m)  (cm)  (deg)    (N)                (N.m)               
  -------------------------------------------------------------------------------------------------------------------------------
  1    CLARK Z AIRFOIL | NACA 0015                |   1.668  3.95 0.457   5.4   2.00   22.1  11.1  1.199   -1.18       ok 0.288
  2    GOE 384 AIRFOIL | NACA 0015                |   1.448  3.70 0.425   8.3   2.00   25.1   9.8  1.381   -3.95       ok 0.290
  3    CLARK Z AIRFOIL | S1048 14% (Danny Howell) |   1.668  3.95 0.457   5.4   2.00   22.2  11.0  1.199   -0.76       ok 0.295
  4    GOE 384 AIRFOIL | S1048 14% (Danny Howell) |   1.448  3.70 0.425   8.3   2.00   25.2   9.7  1.381   -3.52       ok 0.297
  5    CLARK Z AIRFOIL | NACA 63-015A AIRFOIL     |   1.668  3.95 0.457   5.4   2.00   22.2  11.0  1.199    0.07 NOSE-UP! 0.298
  6    GOE 384 AIRFOIL | NACA 63-015A AIRFOIL     |   1.448  3.70 0.425   8.3   2.00   25.2   9.7  1.381   -2.65       ok 0.299
  7    GOE 384 AIRFOIL | NACA 642-015A AIRFOIL    |   1.448  3.70 0.425   8.3   2.00   25.2   9.7  1.381   -2.20       ok 0.300
  8    CLARK Z AIRFOIL | NACA 0018                |   1.668  3.95 0.457   5.4   2.00   22.3  11.0  1.199    0.13 NOSE-UP! 0.303
  9    CLARK Z AIRFOIL | NACA 642-015A AIRFOIL    |   1.668  3.95 0.457   5.4   2.00   22.2  11.0  1.199    0.50 NOSE-UP! 0.304
  10   CLARK Z AIRFOIL | S1046 17% (Danny Howell) |   1.668  3.95 0.457   5.4   2.00   22.3  11.0  1.199   -0.09       ok 0.305
  11   CLARK Z AIRFOIL | E169  (14.4%)            |   1.668  3.95 0.457   5.4   2.00   22.3  11.0  1.199   -1.10       ok 0.305
  12   GOE 384 AIRFOIL | NACA 0018                |   1.448  3.70 0.425   8.3   2.00   25.3   9.7  1.381   -2.58       ok 0.305
  13   GOE 384 AIRFOIL | E169  (14.4%)            |   1.448  3.70 0.425   8.3   2.00   25.3   9.7  1.381   -3.87       ok 0.308
  14   GOE 384 AIRFOIL | S1046 17% (Danny Howell) |   1.448  3.70 0.425   8.3   2.00   25.3   9.7  1.381   -2.82       ok 0.308
  15   CLARK Z AIRFOIL | E475  (15.01%)           |   1.668  3.95 0.457   5.4   2.00   22.4  10.9  1.199   -1.85       ok 0.310
  16   GOE 384 AIRFOIL | E475  (15.01%)           |   1.448  3.70 0.425   8.3   2.00   25.4   9.7  1.381   -4.65       ok 0.311
  17   CLARK Z AIRFOIL | E474  (14.09%)           |   1.668  3.95 0.457   5.4   2.00   22.4  10.9  1.199   -1.94       ok 0.312
  18   GOE 384 AIRFOIL | E474  (14.09%)           |   1.448  3.70 0.425   8.3   2.00   25.4   9.7  1.381   -4.75       ok 0.313
  19   GOE 624 AIRFOIL | NACA 0015                |   1.605  3.88 0.448   7.2   2.00   23.3  10.5  1.245   -0.20       ok 0.313
  20   CLARK Z AIRFOIL | EPPLER 479 AIRFOIL       |   1.668  3.95 0.457   5.4   2.00   22.4  10.9  1.199   -0.87       ok 0.314
  21   GOE 384 AIRFOIL | EPPLER 479 AIRFOIL       |   1.448  3.70 0.425   8.3   2.00   25.5   9.6  1.381   -3.63       ok 0.318
  22   GOE 384 AIRFOIL | NACA 0021                |   1.448  3.70 0.425   8.3   2.00   25.5   9.6  1.381   -1.41       ok 0.318
  23   GOE 384 AIRFOIL | GOE 775 AIRFOIL          |   1.448  3.70 0.425   8.3   2.00   25.5   9.6  1.381   -0.99       ok 0.321
  24   GOE 624 AIRFOIL | S1048 14% (Danny Howell) |   1.605  3.88 0.448   7.2   2.00   23.4  10.5  1.245    0.21 NOSE-UP! 0.322
  25   CLARK Z AIRFOIL | NACA 0021                |   1.668  3.95 0.457   5.4   2.00   22.5  10.9  1.199    1.24 NOSE-UP! 0.326
  26   CLARK Z AIRFOIL | EPPLER 473 AIRFOIL       |   1.668  3.95 0.457   5.4   2.00   22.6  10.8  1.199   -1.92       ok 0.328
  27   GOE 384 AIRFOIL | EPPLER 473 AIRFOIL       |   1.448  3.70 0.425   8.3   2.00   25.6   9.6  1.381   -4.72       ok 0.329
  28   GOE 681 AIRFOIL | NACA 0015                |   1.609  3.89 0.448   7.6   2.00   23.5  10.5  1.243   -3.92       ok 0.330
  29   GOE 624 AIRFOIL | E169  (14.4%)            |   1.605  3.88 0.448   7.2   2.00   23.5  10.4  1.245   -0.12       ok 0.330
  30   GOE 384 AIRFOIL | US1000ROOT               |   1.448  3.70 0.425   8.3   2.00   25.5   9.6  1.381    1.22 NOSE-UP! 0.331
  -------------------------------------------------------------------------------------------------------------------------------

  Best overall: CLARK Z AIRFOIL + NACA 0015
  Smallest wing: GOE 384 AIRFOIL
  Lowest drag:   CLARK Z AIRFOIL
  Best L/D:      CLARK Z AIRFOIL

====================================================
  Full sizing output - best candidate: CLARK Z AIRFOIL + NACA 0015

====================================================
    Aircraft Initial Sizing Results
====================================================

  ISA Atmosphere
    Altitude              1200.0  m
    Density               1.0900  kg/m3
    Temperature           280.35  K
    Dynamic pressure      340.61  Pa

  Main Wing
    - Airfoil:          CLARK Z AIRFOIL
    - Incidence:        1.0 deg
    - Span:             3.953 m
    - Effective span:   3.653 m  (span - fuselage)
    - Chord:            0.457 m
    - Area (eff):       1.6676 m2
    - Area (gross):     1.8046 m2
    - AR (eff):         8.00
    - CL_alpha (3D):    4.4850 rad^-1
    - CL_max (3D):      1.1990
    - Oswald e:         0.8106
    - Thickness:        11.8 %c  (5.4 cm)

  Tail (V-Tail)
    - Airfoil:          NACA 0015
    - Dihedral:         35.0 deg
    - Projected span:   1.100 m
    - Geometric span:   1.343 m
    - Chord:            0.280 m
    - Area:             0.3760 m2
    - AR:               4.80
    - CL_alpha (3D):    4.1116 rad^-1
    - Oswald e:         0.9074
    - Thickness:        15.0 %c  (4.2 cm)
    - V_h (eff):        0.465  (ok)
    - V_v:              0.0376  (ok)
                         Sailplane  Homebuilt  GA-single  GA-twin
              V_h ref:     0.50       0.48       0.67      0.81
              V_v ref:     0.019      0.038      0.044     0.066

  Cruise State (tail incidence FIXED)
    Tail incidence          2.00  deg  (OVERRIDE)
    Fuselage AoA           -0.04  deg
    Wing geo. AoA           0.96  deg
    Downwash eps            0.37  deg
    Tail eff. AoA           1.58  deg
    Wing CL               0.4100
    Tail CL               0.1169
    Thrust moment           4.50  N.m  (nose-up)
    Moment imbalance        2.54  N.m  (nose-up)

  Stall Condition  (wing at CL_max, tail fixed from cruise trim)
    Fuselage AoA           10.04  deg
    Wing geo. AoA          11.04  deg
    Downwash eps            1.09  deg
    Tail eff. AoA          10.94  deg
    Wing CL               1.1990  (= CL_max_3d)
    Tail CL               0.7885
    Tail lift (vert)       29.78  N
    Pitch moment           -1.18  N.m  NOSE-DOWN (safe)
    Neutral i_tail          1.62  deg  (M=0 at stall)

  Fuselage  (conical nose + cylinder, base recovery 34%)
    Fineness ratio          3.33
    Form factor FF        2.6283
    Re (fuselage)      1.556e+06
    Cf (turbulent)       0.00412
    Swet nose             0.1581  m2
    Swet cylinder         0.6597  m2
    Swet total            0.8178  m2
    Friction drag           3.02  N
    Base drag (full)        6.53  N
    Base drag (resid)       4.31  N
    Fuselage total          7.32  N

  Drag (cruise)
    Wing profile            3.88  N
    Wing induced            4.69  N
    Tail profile            0.97  N
    Tail induced            0.13  N
    Fuselage                7.32  N
    Misc (x1.30)           5.10  N
    Total drag             22.09  N
    Total lift            245.17  N
    L/D                    11.10

  Lift & Drag vs AoA
     AoA      Lift      Drag      L/D
      0°     247.3      22.2     11.1
      1°     298.8      25.3     11.8
      2°     350.2      29.1     12.0
      3°     401.7      33.8     11.9
      4°     453.1      39.2     11.6
      5°     504.6      45.4     11.1
      6°     556.0      52.3     10.6
      7°     607.5      60.1     10.1
      8°     658.9      68.6      9.6
      9°     710.4      77.9      9.1
     10°     761.8      88.0      8.7
     11°     813.3      98.9      8.2
     12°     864.8     110.5      7.8
     13°     916.2     122.9      7.5
     14°     967.7     136.1      7.1

====================================================

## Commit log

2026-03-25 Add build123d dependency and design module
    Set up src/design/ for parametric CAD work with build123d.
2026-04-01 Add initial aerodynamic sizing toolchain
    Sizing toolchain for wing area, tail incidence, cruise drag, and stall
    behavior analysis. Sweeps 1,634 airfoils from XFOIL database across all
    wing+tail combinations with configurable scoring.
    Features:
    - Single config.py entry point for all inputs (MODE 1=sweep, 2=sizing)
    - V-tail and conventional tail support with V_h/V_v volume coefficients
    - 3D lift corrections (Helmbold lift slope, cl_0 zero-lift angle preservation)
    - Hoerner 3D base drag with pusher prop recovery factor (CFD-calibrated)
    - Drag polar fit (cd_min + k*(alpha-alpha_minD)^2) from XFOIL database
    - Oratex skin compatibility filter (concave lower surface exclusion)
    - L/D vs AoA sweep o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
    [airfoil_db_re1000000.csv, airfoil_db_re500000.csv, oratex_compatibility.csv]
2026-04-01 Add wing/tail characteristic lists and fix import paths
    - Output now shows airfoil name, incidence, dihedral, thickness for both
    wing and tail as a clean characteristic list
    - Tail airfoil name and thickness shown in sweep detail output
    - Fix sys.path import order so v2 modules take priority over parent
2026-04-01 Add propulsion model for engine and propeller performance
    2-stroke engine model with fixed-pitch propeller thrust, fuel consumption,
    endurance sizing, and transition simulation for the RCGF Stinger 35cc RE.
    - Power curve from volumetric efficiency model anchored to rated HP
    - Static thrust via RPM^(4/3) scaling anchored to manufacturer test point
    - In-flight thrust via Ct(J) quadratic model with eta_pitch correction
    - Cruise RPM solver (thrust = drag bisection)
    - Prop comparison table across multiple diameter/pitch candidates
    - Transition simulation (1D Euler integration to cruise speed)
    - Thermal efficiency validated against published 2-stroke data (16% at 520 g/kWh)
    - Fix: density ratio n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
2026-05-23 Add preliminary design information note
    Preliminary exterior geometry of the fuselage, main wing, inverse V-tail, and longitudinal booms, with isometric, side, front, and top views. Located under docs/Info-Note/Aerodynamics/0001-Preliminar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
2026-05-23 Add CAD and sizing source files; move view images under assets
    Adds fuselage, main wing, tail, and boom STEP models, the sizing config, and the sweep results under assets/. Moves the four view images to assets/images/ and updates the note links.
    [fuselage.step, longitudinal_booms.step, main_wing.step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]
2026-05-23 Add aerodynamic database note and SakeDB tool
    [Stocks.csv, actuator_disk_results.csv, actuator_disk_results_symmetric.csv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]
2026-05-23 Move SakeDB tool under src tools
    [Stocks.csv, breast_cancer.csv, data_x_x2_x3.csv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]
2026-05-25 Update aerodynamic notes and tools
    [actuator_disk_results.csv, actuator_disk_results_symmetric.csv, beta0_lift_drag_vs_aoa_alpha_m4_20.csv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]
2026-06-08 Build Nondimit macOS package
    [stability_modes.csv]
2026-06-11 Add preliminary stability analysis information note
    [nondimit_moment_transfer_check.csv, stability_metrics_summary.csv, stability_modes_summary.csv]
2026-07-20 docs: address review comments — Arrow Air → Arrow, correct skin to Oratex fabric
2026-07-20 docs: clean up Docusaurus sidebar — frontmatter labels, category files, heading hygiene
    - Add title/sidebar_label/sidebar_position frontmatter to all docs
    - Add _category_.json files: Information Notes, Phase 1, Aerodynamics,
    Flight Dynamics, Reference Guides, collapsed Case Reports
    - Demote template-section H1s (Status, Methodology, ...) so each page
    has a single H1 and a working table of contents
    - Fix stale Phase 2 TOC anchor in electrical master
2026-07-20 ci: exclude vendored, generated, and data files from editorconfig check
    The Code Style sanity check has been failing on main with ~33.5K errors,
    nearly all from files that were never hand-written for this repo:
    - src/tools/ — vendored Python runtimes (SakeDB/_internal), PyInstaller
    build output (Nondimit/macos), __pycache__, airfoil .dat geometry sets,
    and tool sources whose only violations are alignment inside docstrings
    - docs/**/assets and docs/**/data — copied analysis artifacts (.step,
    .csv, sweep results) that document a run, not living code
    - .DS_Store files
    With these excludes the check goes from 33,531 errors to 0, so it can
    actually catch regressions in docs and top-lev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
2026-07-20 ci: fix spelling check — ignore vendored/data paths, add domain words
    Spelling was failing on the same vendored runtimes and data artifacts as
    the editorconfig check, plus ~165 legitimate domain terms (ArduPilot
    params, vendor names, aero terminology, contributor names) that were
    never added to the project word list.
    - .cspell.config.yaml: ignore src/tools, docs assets/data, .DS_Store.
    Marked as repo-local additions since the file is provisioned from
    tf-github — needs upstreaming or re-adding if re-provisioned.
    - .cspell.project-words.txt: add reviewed unknown words (all verified as
    real part numbers, ArduPilot parameters, vendors, or people — no typos
    whitelisted).
    Local run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
2026-07-20 ci: add words missing from the older cspell dictionaries in CI
    The docker image's cspell is older than current npm cspell and lacks
    common technical terms (GPIO, GNSS, bitmask, ...) that newer bundled
    dictionaries include.
2026-10-15 feat(fdm): validate normally armed ArduPlane fixed-wing control
2026-10-15 feat(fdm): connect web Flight Deck to owned SITL runs and PWM replay
2026-10-15 feat(fdm): add PT1 propulsion and ground-start Flight Deck sessions
    Integrate October control data, aircraft-specific session setup, QuadPlane
    mode controls, the external FDM view, and the PT1 21 kg MAD pusher estimate.
    Add normally armed ArduPlane 4.7.1 ground takeoff/hover/land missions and
    compact validation deliverables.
    Update setup and runtime documentation. Validation: 299 FDM tests passed;
    recorded 5, 10 and 20 m ground missions passed. Local binaries and raw
    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
2026-10-15 feat(fdm): October reference restore, sparse controls, transition runners, Ankara SITL home
    Checkpoint of the 11-14 October work that was still uncommitted:
    - Restore the October base table numerically from the Nondimit export
    center (-0.1, 0, +0.15) to the CFD origin and transfer moments once to CG.
    - Load the 11 October 103-case control delivery as sparse alpha/deflection
    planes with speed interpolation and the measured elevator/rudder residual.
    - Add hover-to-FBWA and FBWA-to-hover diagnostics, hover and forward
    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
2026-10-15 feat(fdm): drawing rotor geometry, separate PT1 and PT1.5 profiles, lift battery telemetry
    - Lift rotors and pusher follow the 14 October drawing: rotors at
    x = +0.675 / -0.750 m, y = +/-0.55 m, z = -0.043 m (centroid -0.0375 m);
    pusher at (-0.374, 0, +0.050) m, the lowest open mount height. The
    nominal +0.55 / -0.85 m rectangle is withdrawn.
    - pt1_as_built is now PT1 as flown in log17 (17.9 kg, wings on, no pusher,
    CG x -0.0475 m from the logged hover share). pt15 is PT1.5 (21 kg,
    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
2026-10-15 feat(fdm): Flight Deck test tools - wind, failures, live alerts, CG summary, log comparison
    - Wind: uniform steady wind plus 1-cosine gusts (NED, meteorological
    direction). Aerodynamics, pusher inflow and the simulated pitot use the
    air-relative velocity; wind starts at release (ground: lift spin-up) so
    the pitot calibration sees still air. Records carry wind, airspeed,
    alpha and beta from the air-relative velocity.
    - Failure injection after release: any lift motor out, pusher cut; low
    battery is wired but disabled until the SITL battery parameters are
    approved. Records keep commanded and applied control.
    - Live alerts in Fly: elevator beyond the measured +/-15 deg, pusher above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
2026-10-15 fix(fdm): physical consistency review against the September aero notes
    - Flag forward flight between 3 and 20 m/s: the neutral table is from
    25 m/s, while the 10 and 15 m/s neutral cases show much lower lift
    (CL at alpha 0: 0.08 / 0.27 vs 0.36), likely the fixed 30 N pusher
    slipstream over the tail. Asked as AQ-18 in the Aero clarification note.
    - Label the reference design (ADB v1.1, static margin about -17 % at its
    CG) and its fixed-wing SITL configs (CG 0.45 m below the origin,
    outside the fuselage) as software-regression only.
    - Validation summary records the checks that passed: control signs,
    sideslip antisymmetry, no double-counted pusher thrust.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
2026-10-15 docs: 14 October update summary and Flight Dynamics note 0003 (hover and fixed-wing assessment)
    - FDM docs/update_2026_10_14.md: what changed, why, migration notes,
    verification and open items; linked from the FDM README.
    - Flight Dynamics note 0003: PT1 log results, hover headroom and yaw,
    CG window, trim and pusher performance, dynamic modes, SITL transition
    results, limitations and recommendations.
    - Log-derived PT1 CG uncertainty stated as about +/-20 mm (single wings-on
    segment; wingless segments spread -0.067 to -0.008 m).
    Claude-Session: https://claude.ai/code/session_01VM2m3qD2x6Pt1mSjvNjvTG
2026-10-15 docs: hover and fixed-wing input responses in Flight Dynamics note 0003 (Rev B)
    - Hover pitch/roll/yaw/collective and 22 m/s elevator/aileron/rudder/pusher
    doublets in ArduPlane 4.7.1 SITL at the PT1.5 target CG; figures and a
    compact metrics file in the note folder (raw recordings stay local).
    - Findings: pitch and roll well damped; hover yaw sluggish and lightly
    damped; Dutch roll from the doublets matches the linear mode; strong
    adverse yaw; 2.1 deg rudder trim traced to lateral loads in the 15 m/s
    elevator increments (limitation, fix proposed, not applied).
    - scripts/analyse_input_responses.py reproduces the metrics and figures.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
2026-10-15 fix(fdm): runner wall-clock allowance includes the firmware startup
    The hover and forward runners allowed five times the flight duration of
    host time, but about 50 simulated seconds of calibration, EKF start, arming
    and motor start come first. A 60 s hover at 0.33x real time (fresh clone on
    a two-core machine) therefore timed out at 99 of 107 simulated seconds.
    default_wall_timeout() now allows five times duration plus 60 s; only the
    host deadline changes. The setup guide notes --wall-timeout.
    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
2026-10-15 fix(gui): flight plots and messages count time from release
    Flight plots used the simulator clock, which includes about 47 s of
    calibration, arming and motor start, so a 60 s run ran to about 107 s on the
    axis. Plots now put 0 at release (ground starts: free physics start), show
    startup at negative times and mark release with a dotted line; messages read
    T-/T+ from release; the live progress label says 'Simulator clock'.
    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
2026-10-15 test(gui): lift plot limits test ignores the release marker
    The release line added to the flight plots is a vertical shape; the lift
    PWM limit check now counts horizontal limit lines only. Full suite: 562
    passed.
    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
2026-10-15 docs(fdm): consolidate documentation into six English documents
    The FDM docs are now README, setup guide, Flight Deck guide, SITL
    integration, model reference, validation summary and the changes relative
    to main.
    - flight_deck.md merges the ground-control, test-tools and ground-start
    guides and the experiment part of capabilities.
    - sitl_integration.md replaces the Turkish SITL quickstart and plan with an
    English description of the firmware pinning, protocol, channels, sensors,
    startup, runners with pass criteria and recorded files.
    - model_reference.md merges aircraft profiles, mass baselines, the October
    AeroDB note and main's PR #7 and stability-gap notes; stale history and
    ref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
2026-10-16 feat(fdm): selectable PT1.5 pusher motor - KDE5215XF-220 alongside MAD V8013
    - pt15 profile: propulsion.pusher.options {mad, kde} with selected: mad.
    KDE option = KDE5215XF-220 with KDE-UAS75HVC+ (the lift motor and ESC),
    wooden 20x12 propeller modelled with APC's 20x12 Sport map like MAD.
    - KDE electrical constants fitted to the motor's 28-point static test
    (scripts/fit_kde_pusher_motor.py -> data/propulsion/kde5215xf_220_pusher_fit.json):
    Kv 220, I0 1.84 A, R_eq 0.136 ohm, plus a measured throttle-to-duty map
    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
2026-10-29 Add information note 0003: Updated Aerodynamic Database
    Updated aerodynamic database replacing 0002: 400-case neutral-control CFD database with the actuator disk in every run, Nondimit coefficient table about the CG (-0.10, 0, 0.15), control surface defle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
